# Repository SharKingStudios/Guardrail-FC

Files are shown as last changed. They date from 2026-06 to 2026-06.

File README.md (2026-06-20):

# Guardrail FC - A Flight Assist that helps you not crash!

### With a side of data logging and autopilot.

---

## Renders
*visuals because everyone loves eye candy.*

<p align="center">
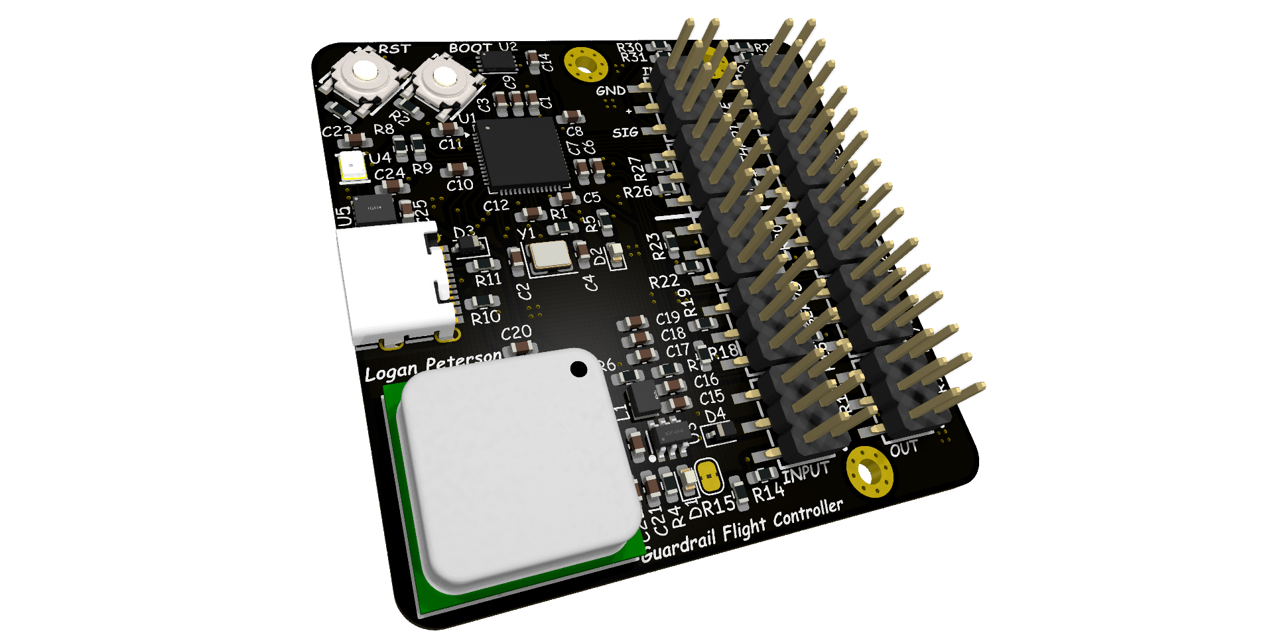
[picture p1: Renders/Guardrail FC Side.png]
Side PCB Render
  
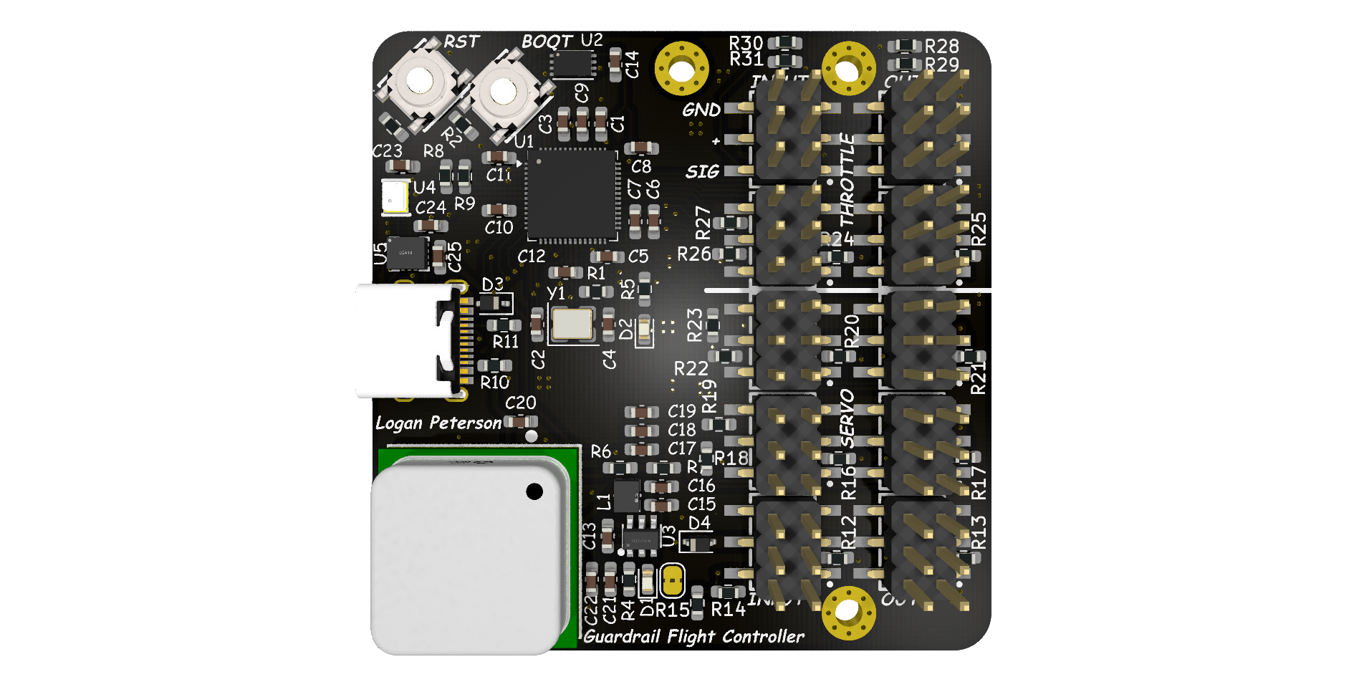
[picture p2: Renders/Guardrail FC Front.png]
Front PCB Render
  
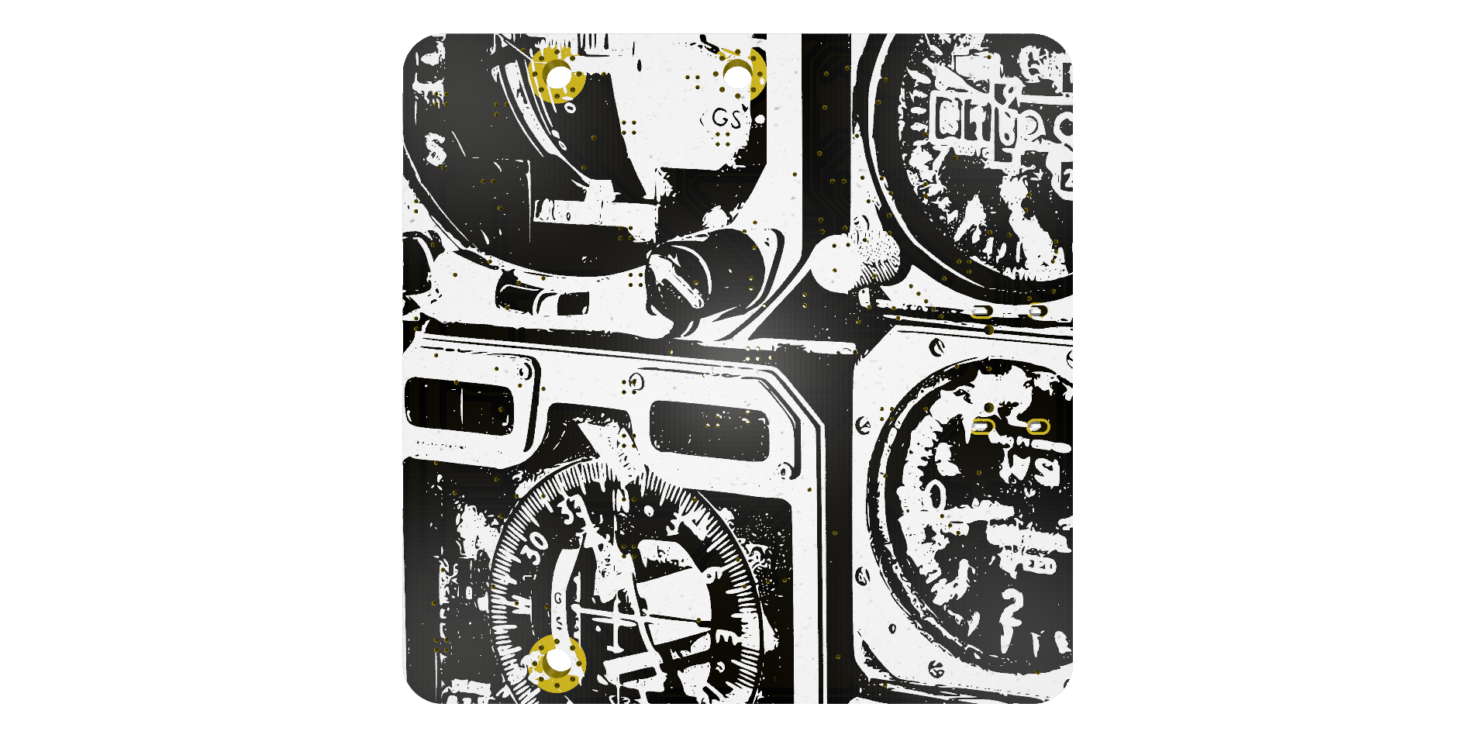
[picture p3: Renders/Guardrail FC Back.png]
Back PCB Render
  
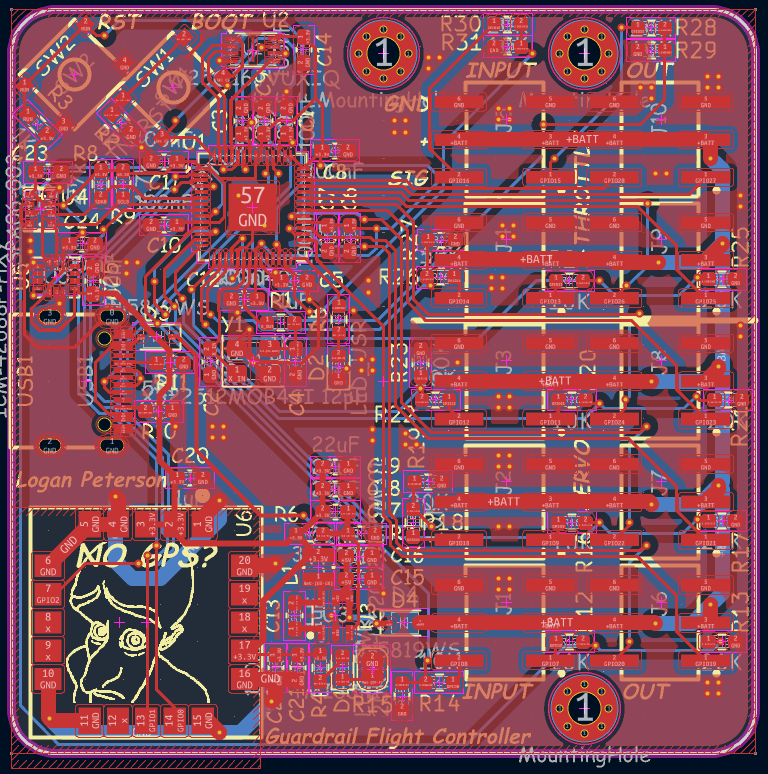
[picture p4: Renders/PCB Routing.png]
PCB Routing
  
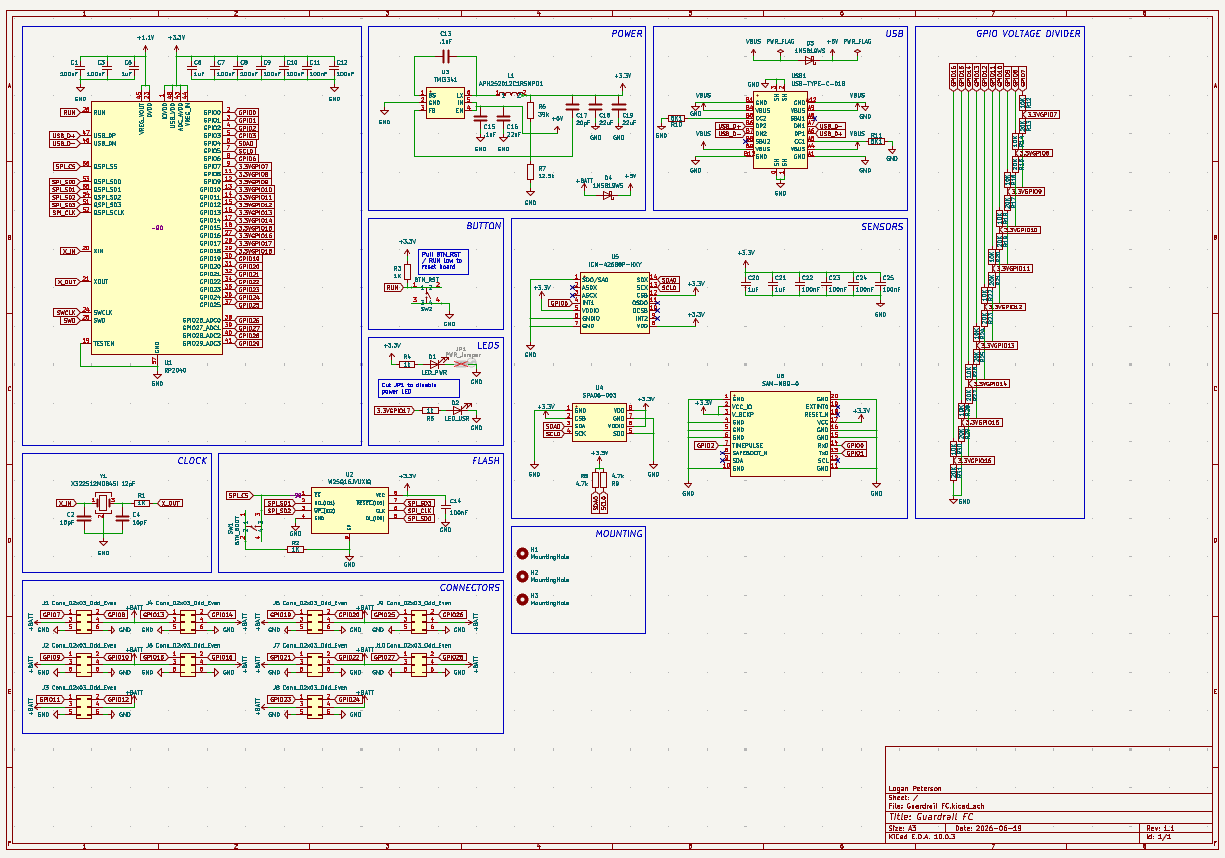
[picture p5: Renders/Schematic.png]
PCB Schematic
  
</p>

---

## BOM
All the sensing and thinky bits live **[here](/BOM.csv)**.

**Main characters:**
 - **Microcontroller:** RP2040
 - **Storage:** W25Q16JVUXIQ 16Mbit SPI flash
 - **Sensors:**
   - ICM-42688P-HXY 6-axis IMU
   - SAM-M8Q-0 GNSS module
   - SPA06-003 pressure sensor
 - **Misc:** Boot circuitry, pull-ups, decoupling, and other necessary magic

(See `BOM.csv` for full part values, footprints, and sourcing.)

---

## What is this?

The **Guardrail FC** is a **Flight Controller** built around a RP2040 microcontroller and a handful of sensors, designed to help you not crash your RC planes and drones!

It does this by sitting in the middle of the data signals between the RC reciever and the plane's control surfaces / throttle. The board will use the pilot's input to steer the plane, but will lock the plane to certain bank angles in order to prevent the plane from flipping upside down and crashing. The board also logs all the sensor data and pilot inputs to its onboard flash, which can be retrieved after the flight to analyze flight characteristics afterwards.

---

## How It Works

On startup, the board will continuously read the IMU, GNSS, and pressure sensors to get an idea of the plane's orientation, position, and altitude. From these readings, the board calculates what angles the servos need to be at to get to a certain desired angle using a PID loop.

The board will then read the pilot's input from the RC receiver, and use that to control the desired angle for the plane.

At a high level:
1. Read sensors to get current orientation, position, and altitude.
2. Read pilot input to get desired angle.
3. Use PID loop to calculate servo angles needed to achieve desired angle.
4. Output servo angles to control surfaces and throttle.

---

## Features

### Flight Assist
The main feature of the Guardrail FC is its flight assist capabilities. By using the IMU data, the board can determine the plane's current orientation and adjust the control surfaces to keep the plane within a certain bank angle, preventing it from flipping upside down and crashing.

### Data Logging
The board logs all sensor data and pilot inputs to its onboard flash memory. This allows you to analyze flight characteristics after the flight.

### Autopilot
In addition to flight assist, the firmware includes a guarded automatic-throttle mode that uses pressure altitude, vertical speed, aircraft attitude, and optional GNSS ground speed. Waypoint navigation remains future work.

---

## Firmware

The firmware lives in **[`Firmware/`](/Firmware/)** and is written in Python using MicroPython. Interrupt-driven input capture keeps all ten receiver channels live while the controller reads sensors and logs the flight.

See the [`Firmware/README.md`](/Firmware/README.md) for more details on how to set up the firmware and tune the board for your specific plane.

---

### Why?

Because crashing is bad, and this board helps you not crash! I've had an interest in RC planes and drones for a while, and by making this board, I can run whatever kind of firmware I want to create interesting flight characteristics. One of my friends recently created and crasshed their custom built plane, and I wanted to make something that might have been able to save it!

---

## Contributing

This is a personal project, but if you have any ideas or suggestions, feel free to open an issue or submit a pull request! I'm always open to feedback and improvements.

## Disclaimer

This project is still in development, and I have yet to test it in flight. Remember to test in a safe environment before flying with hardware from a random internet person! I am not responsible for any crashes or damage caused by this board. Use at your own risk!

<p align="center">
  Zine Page!
</p>

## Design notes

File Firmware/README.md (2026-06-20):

# Guardrail FC firmware

The v1 firmware is a configurable, fail-safe signal router, flight-assist controller, and flight logger for the Guardrail FC PCB. It uses MicroPython on the RP2040 so all 10 receiver PWM channels can be captured concurrently with hardware interrupts. The RP2040 CircuitPython port cannot provide enough simultaneous pulse-capture channels for this board's 10 inputs.

The safe factory profile is intentionally boring: J1-J3 pass straight through to J6-J8, J4/J5 throttle passes straight through to J9/J10, and both flight assist and AUTO throttle stay unselected until the airframe mapping and correction directions have been bench-tested.

## Files

- `main.py` initializes hardware and runs the real-time loop.
- `config.py` contains every normal airframe-specific choice and tuning value.
- `guardrail/channels.py` captures receiver pulses and drives servo PWM.
- `guardrail/control.py` performs routing, surface mixing, roll/pitch PID control, and guarded automatic throttle.
- `guardrail/sensors.py` reads the ICM-42688-P and SPA06-003 directly over I2C.
- `guardrail/gnss.py` parses GGA/RMC messages from the SAM-M8Q.
- `guardrail/logger.py` writes compact `.grf` flight logs to onboard flash.
- `tools/decode_log.py` converts a downloaded `.grf` file to CSV.

No third-party modules are needed on the controller.

## Install

1. Install the current RP2040 build of MicroPython while holding BOOT and connecting
   USB. The generic Raspberry Pi Pico build matches the RP2040 and 2 MiB W25Q16 flash.
2. Install `mpremote` on the computer: `python -m pip install mpremote`.
3. Copy `main.py`, `config.py`, and the entire `guardrail/` directory to the board.
4. Reset the board and watch the serial console. It prints the I2C scan, sensor status,
   gyro calibration result, log filename, and active mode.

Keep the aircraft motionless for roughly one second after reset. Outputs stay at their configured failsafe values during gyro calibration. Set `AUTO_GYRO_CALIBRATION = False` and enter measured `GYRO_BIAS_DPS` values if that startup pause is undesirable.

## Configure an airframe

Only edit `config.py`. The names stay tied to physical connector sides, so an output can be reassigned without remembering GPIO numbers.

For a one-to-one route, use:

```python
"J6_LEFT": _direct("J2_RIGHT")
```

For a reversed servo with roll stabilization mixed in:

```python
"J6_RIGHT": _direct("J1_RIGHT", assist={"roll": -1.0}, reverse=True)
```

For an elevon or V-tail, replace `source` with weighted `sources` in that output:

```python
"J6_LEFT": {
    "sources": {"J1_LEFT": 1.0, "J2_LEFT": 1.0},
    "assist": {"roll": 1.0, "pitch": 1.0},
    "reverse": False,
    "trim_us": 0,
    "min_us": 1000,
    "center_us": 1500,
    "max_us": 2000,
    "failsafe_us": 1500,
    "passthrough": False,
}
```

This same weighted mapping handles dual ailerons, flaperons, V-tails, canards, and multiple motor sections. A receiver channel may feed any number of outputs, and an output may combine any number of non-throttle inputs. A J4/J5 throttle may feed any number of J9/J10 motor outputs. Those routes remain exact pass-through in PASSTHROUGH and ASSIST modes; only AUTO may override the configured motor outputs.

Set `CONTROL_AXES` to the receiver channels that command roll and pitch. Add `roll`
or `pitch` assist weights only to surfaces that should correct that axis. Verify every
sign with the propellers removed:

- Roll the right wing down; the commanded surfaces must drive it back up.
- Raise the nose; the elevator correction must command nose-down.
- Move every transmitter stick and confirm the expected output and direction.
- Turn the transmitter off and confirm control surfaces center and all throttles go low.

Only after those checks should `DEFAULT_MODE` be changed to `"ASSIST"`. Prefer assigning
a spare three-position receiver channel to `MODE_CHANNEL`: low selects PASSTHROUGH,
middle selects ASSIST, and high selects AUTO. Begin with low `kp`, leave `ki` near zero, increase `kp` until the
aircraft responds firmly, add `kd` to reduce oscillation, and add only enough `ki` to
remove steady bias. Change one axis and one gain at a time.

`IMU_AXIS_MAP` handles rotated or inverted board installations without changing sensor
code. Confirm the printed/logged roll and pitch signs before enabling assist.

## Automatic throttle

AUTO uses every useful onboard measurement without pretending the board has an
airspeed sensor:

- SPA06 pressure altitude is the primary feedback. AUTO captures the current altitude
  when selected unless `target_altitude_m` is configured explicitly.
- Vertical speed derived from pressure altitude damps throttle changes and reduces
  overshoot.
- ICM-42688 roll adds throttle in a bank, while positive pitch adds configurable climb
  feed-forward.
- SAM-M8Q ground speed can add a bounded correction when `groundspeed_target_mps` is
  configured. It is disabled by default because ground speed is not stall-protecting
  airspeed in wind.

All airframe values are in `AUTO_THROTTLE` in `config.py`. Tune `cruise_us`, `min_us`,
and `max_us` first with AUTO disabled. Then set a conservative `slew_rate_us_per_s`,
start with altitude `ki` at zero, and tune altitude `kp` at a safe height. Add vertical
speed damping, then only enough integral to remove a steady altitude error. Bank and
pitch compensation are feed-forward terms and should be tuned last.

The `outputs` map selects which J9/J10 motor sections AUTO controls and supplies a
per-motor trim. Outputs not listed remain pilot pass-through. AUTO will arm only on the
transition into AUTO when:

- every receiver channel feeding an automatic motor output is fresh;
- a valid barometric altitude is available (or explicitly enabled GNSS fallback);
- the IMU is healthy when `require_imu` is true; and
- GNSS is valid when GNSS ground-speed control is configured.

If any required input disappears after engagement, all automatic motor outputs go to
their configured low-throttle failsafe and AUTO will not re-arm until the mode switch is
toggled out and back. Moving any pilot throttle above `pilot_override_us` immediately
restores raw pilot throttle and latches that override until AUTO is toggled off/on.
Commands are bounded and slew-limited during normal automatic operation; receiver loss
still takes priority over every override.

Before fitting propellers, select AUTO and verify: throttle enters without a jump,
raising the board decreases the altitude-error command, banking adds only the expected
small compensation, pilot override restores every raw throttle channel, sensor failure
commands low throttle, and re-arming requires a deliberate mode-switch cycle.

## Logs

Logs contain mode (including AUTO), health flags, AUTO-active/pilot-override flags,
attitude, gyro and temperature, pressure altitude, GNSS position/speed/fix, all 10 raw
receiver pulses, and all 10 commanded output pulses. They rotate at 512 KiB; with the
default 10 Hz rate, each file holds roughly ten minutes. Logging stops safely if flash
fills; the control loop continues.

Copy a log from `/logs` with `mpremote`, then decode it on the computer:

```text
python tools/decode_log.py flight_000.grf
```

This produces `flight_000.csv`. Remove old `.grf` files from the controller between test sessions; the W25Q16 is also the firmware/filesystem flash, not a separate recorder.

## Safety status

This is unflown experimental firmware. The LED blinks quickly while any configured
output is in failsafe and slowly when all routed inputs are fresh. Always bench-test with propellers removed, verify PWM limits for every servo/ESC, and test receiver and sensor loss before flight. AUTO throttle is altitude hold, not stall protection or a complete navigation autopilot. A software pass-through cannot protect against total MCU or power failure; a production design that requires that behavior needs an external hardware bypass.

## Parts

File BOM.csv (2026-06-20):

Item | Qty | Price Ea. | Price total (MOQ) | Product Link
0.1uF/100nF capacitor 0603 | 15 | 0.0101 | 1.01 | https://www.lcsc.com/product-detail/C15725.html
15pF capacitor 0603 | 2 | 0.0022 | 0.22 | https://www.lcsc.com/product-detail/C1548.html
1uF capacitor 0603 | 4 | 0.0089 | 0.45 | https://www.lcsc.com/product-detail/C95843.html
22uF capacitor 0603 | 3 | 0.23 | 0.45 | https://www.lcsc.com/product-detail/C59461.html
20pF capacitor 0603 | 1 | 0.0047 | 0.047 | https://www.lcsc.com/product-detail/C105621.html
LED 0603 | 2 | 0.0073 | 0.73 | https://www.lcsc.com/product-detail/C2286.html
1N5819WS Schottky diode SOD-323 | 2 | 0.0107 | 0.54 | https://www.lcsc.com/product-detail/C191023.html
ZHOURI PZ2.54-2*20-SMT | 2 | 0.24 | 1.2 | https://www.lcsc.com/product-detail/C5378173.html
APH252012C1R5MP01 1.5uH SMD inductor | 1 | 0.034 | 0.68 | https://www.lcsc.com/product-detail/C42455360.html
1k resistor 0603 | 5 | 0.0054 | 0.54 | https://www.lcsc.com/product-detail/C2907002.html
39k resistor 0603 | 1 | 0.001 | 0.10 | https://www.lcsc.com/product-detail/C54921034.html
12.5k resistor 0603 | 1 | 0.0016 | 0.16 | https://www.lcsc.com/product-detail/C22866.html
4.7k resistor 0603 | 2 | 0.0017 | 0.17 | https://www.lcsc.com/product-detail/C105428.html
5.1k resistor 0603 | 2 | 0.0022 | 0.22 | https://www.lcsc.com/product-detail/C2907044.html
10k resistor 0603 | 10 | 0.0014 | 0.14 | https://www.lcsc.com/product-detail/C2930027.html
20k resistor 0603 | 10 | 0.0019 | 0.19 | https://www.lcsc.com/product-detail/C2907011.html
LXW-52X52X2-SMD tactile switch | 2 | 0.023 | 0.45 | https://www.lcsc.com/product-detail/C53447014.html
RP2040 microcontroller QFN-56 | 1 | 0.99 | 0.99 | https://www.lcsc.com/product-detail/C2040.html
W25Q16JVUXIQ 16Mbit SPI flash USON-8 | 1 | 2.39 | 11.99 | https://www.lcsc.com/product-detail/C2843335.html
TMI3341 DC-DC converter SOT-23-6 | 1 | 0.13 | 0.68 | https://www.lcsc.com/product-detail/C5182732.html
SPA06-003 pressure sensor LGA-8 | 1 | 0.78 | 0.78 | https://www.lcsc.com/product-detail/C30589048.html
ICM-42688P-HXY IMU LGA-14 | 1 | 3.53 | 3.53 | https://www.lcsc.com/product-detail/C46550687.html
SAM-M8Q-0 GNSS module LCC-20 | 1 | 14.49 | 14.49 | https://www.lcsc.com/product-detail/C5447387.html
USB-TYPE-C-018 USB-C receptacle | 1 | 0.0568 | 0.57 | https://www.lcsc.com/product-detail/C2927038.html
X322512MOB4SI 12pF crystal 3225 4-pin | 1 | 0.0966 | 0.48 | https://www.lcsc.com/product-detail/C70565.html
LCSC Parts Total |  |  | 40.81
LCSC Shipping |  |  | 5.00 | (Bundled with another order)
LCSC Total |  |  | 45.81
JLCPCB 10x10cm 2-layer PCB | 1 | 2.00 | 2.00 | https://jlcpcb.com
JLCPCB 10x10cm stencil | 1 | 7.50 | 7.50 | https://jlcpcb.com
JLCPCB Shipping |  |  | 16.00 | https://jlcpcb.com
JLCPCB Taxes |  |  | 4.00 | https://jlcpcb.com
JLCPCB Total |  |  | 29.50 | https://jlcpcb.com
Overall Total |  |  | 75.31

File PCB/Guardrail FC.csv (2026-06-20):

Reference | Qty | Value | DNP | Exclude from BOM | Exclude from Board | Footprint | Datasheet
C1,C3,C7,C8,C9,C10,C11,C12,C14,C22,C23,C24,C25 | 13 | 100nF |  |  |  | Capacitor_SMD:C_0603_1608Metric_Pad1.08x0.95mm_HandSolder
C2,C4 | 2 | 15pF |  |  |  | Capacitor_SMD:C_0603_1608Metric_Pad1.08x0.95mm_HandSolder
C5,C6,C20,C21 | 4 | 1uF |  |  |  | Capacitor_SMD:C_0603_1608Metric_Pad1.08x0.95mm_HandSolder
C13,C15 | 2 | .1uF |  |  |  | Capacitor_SMD:C_0603_1608Metric_Pad1.08x0.95mm_HandSolder
C16,C18,C19 | 3 | 22uF |  |  |  | Capacitor_SMD:C_0603_1608Metric_Pad1.08x0.95mm_HandSolder
C17 | 1 | 20pF |  |  |  | Capacitor_SMD:C_0603_1608Metric_Pad1.08x0.95mm_HandSolder
D1 | 1 | LED_PWR |  |  |  | LED_SMD:LED_0603_1608Metric
D2 | 1 | LED_USR |  |  |  | LED_SMD:LED_0603_1608Metric
D3,D4 | 2 | 1N5819WS |  |  |  | Diode_SMD:D_SOD-323 | https://datasheet.lcsc.com/lcsc/2204281430_Guangdong-Hottech-1N5819WS_C191023.pdf
J1,J2,J3,J4,J5,J6,J7,J8,J9,J10 | 10 | Conn_02x03_Odd_Even |  |  |  | imported_components:HDR-SMD_6P-P2.54-V
JP1 | 1 | PWR_Jumper | DNP |  |  | Jumper:SolderJumper-2_P1.3mm_Bridged2Bar_RoundedPad1.0x1.5mm
L1 | 1 | APH252012C1R5MP01 |  |  |  | easyeda2kicad:IND-SMD_APH252012C3R3MP01 | https://www.lcsc.com/datasheet/C42455360.pdf
R1,R2,R3 | 3 | 1K |  |  |  | Resistor_SMD:R_0603_1608Metric_Pad0.98x0.95mm_HandSolder
R4,R5 | 2 | 1k |  |  |  | Resistor_SMD:R_0603_1608Metric_Pad0.98x0.95mm_HandSolder
R6 | 1 | 39k |  |  |  | Resistor_SMD:R_0603_1608Metric_Pad0.98x0.95mm_HandSolder
R7 | 1 | 12.5k |  |  |  | Resistor_SMD:R_0603_1608Metric_Pad0.98x0.95mm_HandSolder
R8,R9 | 2 | 4.7k |  |  |  | Resistor_SMD:R_0603_1608Metric_Pad0.98x0.95mm_HandSolder
R10,R11 | 2 | 5K1 |  |  |  | Resistor_SMD:R_0603_1608Metric_Pad0.98x0.95mm_HandSolder
R12,R14,R16,R18,R20,R22,R24,R26,R28,R30 | 10 | 10K |  |  |  | Resistor_SMD:R_0603_1608Metric_Pad0.98x0.95mm_HandSolder
R13,R15,R17,R19,R21,R23,R25,R27,R29,R31 | 10 | 20K |  |  |  | Resistor_SMD:R_0603_1608Metric_Pad0.98x0.95mm_HandSolder
SW1 | 1 | BTN_BOOT |  |  |  | imported_lcsc:SW-SMD_4P-L5.2-W5.2-P5.80-LS6.4 | https://www.lcsc.com/datasheet/C53447014.pdf
SW2 | 1 | BTN_RST |  |  |  | imported_lcsc:SW-SMD_4P-L5.2-W5.2-P5.80-LS6.4 | https://www.lcsc.com/datasheet/C53447014.pdf
U1 | 1 | RP2040 |  |  |  | Package_DFN_QFN:QFN-56-1EP_7x7mm_P0.4mm_EP3.2x3.2mm | https://datasheets.raspberrypi.com/rp2040/rp2040-datasheet.pdf
U2 | 1 | W25Q16JVUXIQ |  |  |  | Package_SON:Winbond_USON-8-1EP_3x2mm_P0.5mm_EP0.2x1.6mm
U3 | 1 | TMI3341 |  |  |  | imported_lcsc:SOT-23-6_L2.9-W1.6-P0.95-LS2.8-BL | https://www.lcsc.com/datasheet/C5182732.pdf
U4 | 1 | SPA06-003 |  |  |  | imported_lcsc:LGA-8_L2.5-W2.0-P0.65_SPA06-003 | https://www.lcsc.com/datasheet/C30589048.pdf
U5 | 1 | ICM-42688P-HXY |  |  |  | imported_lcsc:LGA-14_L3.0-W2.5-P0.50-TL | https://www.lcsc.com/datasheet/C46550687.pdf
U6 | 1 | SAM-M8Q-0 |  |  |  | imported_lcsc:LCC-20_L15.5-W15.5-P1.90_SAM-M10Q-00B | https://www.lcsc.com/datasheet/C5447387.pdf
USB1 | 1 | USB-TYPE-C-018 |  |  |  | imported_lcsc:USB-C_SMD-TYPE-C-31-M-12 | https://www.lcsc.com/datasheet/C2927038.pdf
Y1 | 1 | X322512MOB4SI 12pF |  |  |  | Crystal:Crystal_SMD_3225-4Pin_3.2x2.5mm

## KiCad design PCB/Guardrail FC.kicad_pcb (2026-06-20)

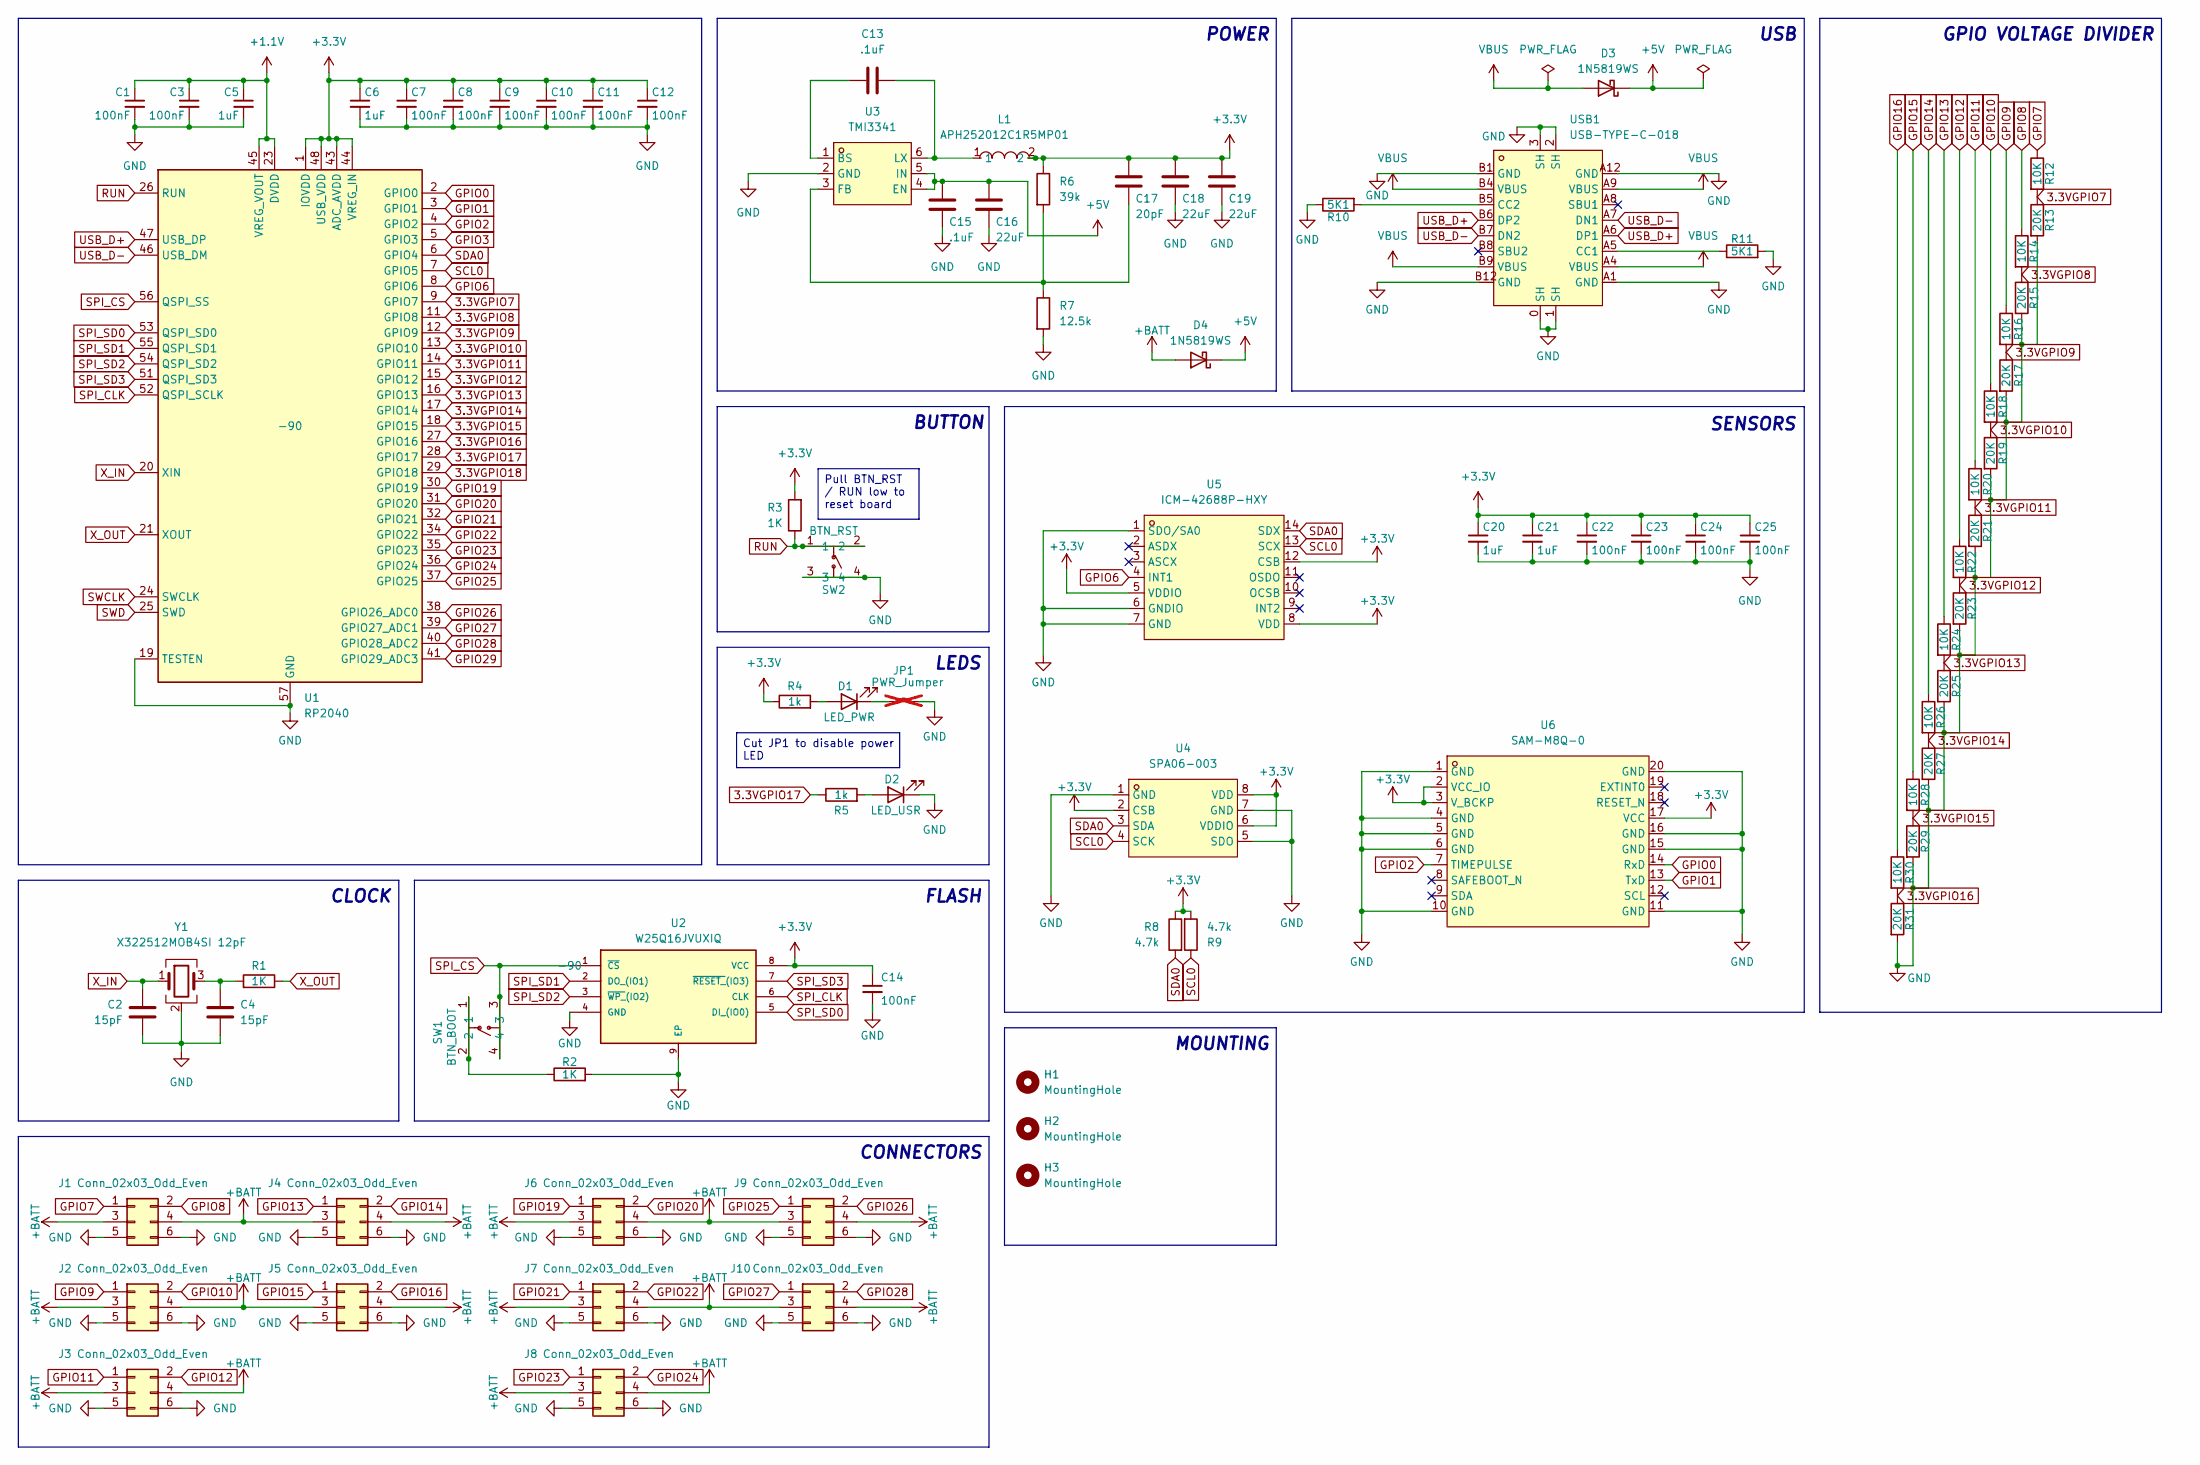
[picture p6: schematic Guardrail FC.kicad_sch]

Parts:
C1, C3, C7, C8, C9, C10, C11, C12, C14, C22, C23, C24, C25: 100nF; C_0603_1608Metric_Pad1.08x0.95mm_HandSolder; LCSC C1525
C2, C4: 15pF; C_0603_1608Metric_Pad1.08x0.95mm_HandSolder; LCSC C1548
C5, C6: 1uF; C_0603_1608Metric_Pad1.08x0.95mm_HandSolder; LCSC C52923
C13, C15: .1uF; C_0603_1608Metric_Pad1.08x0.95mm_HandSolder
C16, C18, C19: 22uF; C_0603_1608Metric_Pad1.08x0.95mm_HandSolder
C17: 20pF; C_0603_1608Metric_Pad1.08x0.95mm_HandSolder
C20, C21: 1uF; C_0603_1608Metric_Pad1.08x0.95mm_HandSolder; LCSC C1525
D1: LED_PWR; LED_0603_1608Metric; LCSC C2286
D2: LED_USR; LED_0603_1608Metric; LCSC C2286
D3, D4: 1N5819WS; D_SOD-323; LCSC C191023
H1, H2, H3: MountingHole; MountingHole_2.2mm_M2_Pad_Via
J1, J2, J3, J4, J5, J6, J7, J8, J9, J10: Conn_02x03_Odd_Even; HDR-SMD_6P-P2.54-V
JP1: PWR_Jumper; SolderJumper-2_P1.3mm_Bridged2Bar_RoundedPad1.0x1.5mm; not fitted
L1: APH252012C1R5MP01; IND-SMD_APH252012C3R3MP01; MPN APH252012C1R5MP01; LCSC Part C42455360
R1, R2, R3: 1K; R_0603_1608Metric_Pad0.98x0.95mm_HandSolder; LCSC C11702
R4, R5: 1k; R_0603_1608Metric_Pad0.98x0.95mm_HandSolder; LCSC C11702
R6: 39k; R_0603_1608Metric_Pad0.98x0.95mm_HandSolder
R7: 12.5k; R_0603_1608Metric_Pad0.98x0.95mm_HandSolder
R8, R9: 4.7k; R_0603_1608Metric_Pad0.98x0.95mm_HandSolder
R10, R11: 5K1; R_0603_1608Metric_Pad0.98x0.95mm_HandSolder; LCSC C25905
R12, R14, R16, R18, R20, R22, R24, R26, R28, R30: 10K; R_0603_1608Metric_Pad0.98x0.95mm_HandSolder; LCSC C11702
R13, R15, R17, R19, R21, R23, R25, R27, R29, R31: 20K; R_0603_1608Metric_Pad0.98x0.95mm_HandSolder; LCSC C11702
SW1: BTN_BOOT; SW-SMD_4P-L5.2-W5.2-P5.80-LS6.4; MPN LXW-52X52X2-SMD; LCSC Part C53447014
SW2: BTN_RST; SW-SMD_4P-L5.2-W5.2-P5.80-LS6.4; MPN LXW-52X52X2-SMD; LCSC Part C53447014
U1: RP2040; QFN-56-1EP_7x7mm_P0.4mm_EP3.2x3.2mm; LCSC C2040
U2: W25Q16JVUXIQ; Winbond_USON-8-1EP_3x2mm_P0.5mm_EP0.2x1.6mm; LCSC C2843335
U3: TMI3341; SOT-23-6_L2.9-W1.6-P0.95-LS2.8-BL; MPN TMI3341; LCSC Part C5182732
U4: SPA06-003; LGA-8_L2.5-W2.0-P0.65_SPA06-003; MPN SPA06-003; LCSC Part C30589048
U5: ICM-42688P-HXY; LGA-14_L3.0-W2.5-P0.50-TL; MPN ICM-42688P-HXY; LCSC Part C46550687
U6: SAM-M8Q-0; LCC-20_L15.5-W15.5-P1.90_SAM-M10Q-00B; MPN SAM-M8Q-0; LCSC Part C5447387
USB1: USB-TYPE-C-018; USB-C_SMD-TYPE-C-31-M-12; MPN USB-TYPE-C-018; LCSC Part C2927038
Y1: X322512MOB4SI 12pF; Crystal_SMD_3225-4Pin_3.2x2.5mm; LCSC C70565

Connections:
3.3VGPIO7: R12.2, R13.1, U1.9 (GPIO7)
3.3VGPIO8: R14.2, R15.1, U1.11 (GPIO8)
3.3VGPIO9: R16.2, R17.1, U1.12 (GPIO9)
3.3VGPIO10: R18.2, R19.1, U1.13 (GPIO10)
3.3VGPIO11: R20.2, R21.1, U1.14 (GPIO11)
3.3VGPIO12: R22.2, R23.1, U1.15 (GPIO12)
3.3VGPIO13: R24.2, R25.1, U1.16 (GPIO13)
3.3VGPIO14: R26.2, R27.1, U1.17 (GPIO14)
3.3VGPIO15: R28.2, R29.1, U1.18 (GPIO15)
3.3VGPIO16: R30.2, R31.1, U1.27 (GPIO16)
3.3VGPIO17: R5.1, U1.28 (GPIO17)
3.3VGPIO18: U1.29 (GPIO18)
+1.1V: C1.1, C3.1, C5.1, U1.23 (DVDD), U1.45 (VREG_VOUT), U1.50 (DVDD)
+3.3V: C6.1, C7.1, C8.1, C9.1, C10.1, C11.1, C12.1, C14.1, C17.2, C18.2, C19.2, C20.1, C21.1, C22.1, C23.1, C24.1, C25.1, L1.2, R3.2, R4.1, R6.1, R8.1, R9.2, U1.1 (IOVDD), U1.10 (IOVDD), U1.22 (IOVDD), U1.33 (IOVDD), U1.42 (IOVDD), U1.43 (ADC_AVDD), U1.44 (VREG_IN), U1.48 (USB_VDD), U1.49 (IOVDD), U2.8 (VCC), U4.2 (CSB), U4.6 (VDDIO), U4.8 (VDD), U5.5 (VDDIO), U5.8 (VDD), U5.12 (CSB), U6.2 (VCC_IO), U6.3 (V_BCKP), U6.17 (VCC)
+5V: C15.2, C16.2, D3.1 (K), D4.1 (K), U3.4 (EN), U3.5 (IN)
+BATT: D4.2 (A), J1.3, J1.4, J2.3, J2.4, J3.3, J3.4, J4.3, J4.4, J5.3, J5.4, J6.3, J6.4, J7.3, J7.4, J8.3, J8.4, J9.3, J9.4, J10.3, J10.4
GND: C1.2, C2.1, C3.2, C4.2, C5.2, C6.2, C7.2, C8.2, C9.2, C10.2, C11.2, C12.2, C14.2, C15.1, C16.1, C18.1, C19.1, C20.2, C21.2, C22.2, C23.2, C24.2, C25.2, D2.1 (K), J1.5, J1.6, J2.5, J2.6, J3.5, J3.6, J4.5, J4.6, J5.5, J5.6, J6.5, J6.6, J7.5, J7.6, J8.5, J8.6, J9.5, J9.6, J10.5, J10.6, JP1.2 (B), R2.2, R7.2, R10.1, R11.2, R13.2, R15.2, R17.2, R19.2, R21.2, R23.2, R25.2, R27.2, R29.2, R31.2, SW2.3, SW2.4, U1.19 (TESTEN), U1.57 (GND), U2.4 (GND), U2.9 (EP), U3.2 (GND), U4.1 (GND), U4.5 (SDO), U4.7 (GND), U5.1 (SDO/SA0), U5.6 (GNDIO), U5.7 (GND), U6.1 (GND), U6.4 (GND), U6.5 (GND), U6.6 (GND), U6.10 (GND), U6.11 (GND), U6.15 (GND), U6.16 (GND), U6.20 (GND), USB1.0 (SH), USB1.1 (SH), USB1.2 (SH), USB1.3 (SH), USB1.A1 (GND), USB1.A12 (GND), USB1.B1 (GND), USB1.B12 (GND), Y1.2 (G), Y1.4 (G)
GPIO0: U1.2 (GPIO0), U6.14 (RxD)
GPIO1: U1.3 (GPIO1), U6.13 (TxD)
GPIO2: U1.4 (GPIO2), U6.7 (TIMEPULSE)
GPIO3: U1.5 (GPIO3)
GPIO6: U1.8 (GPIO6), U5.4 (INT1)
GPIO7: J1.1, R12.1
GPIO8: J1.2, R14.1
GPIO9: J2.1, R16.1
GPIO10: J2.2, R18.1
GPIO11: J3.1, R20.1
GPIO12: J3.2, R22.1
GPIO13: J4.1, R24.1
GPIO14: J4.2, R26.1
GPIO15: J5.1, R28.1
GPIO16: J5.2, R30.1
GPIO19: J6.1, U1.30 (GPIO19)
GPIO20: J6.2, U1.31 (GPIO20)
GPIO21: J7.1, U1.32 (GPIO21)
GPIO22: J7.2, U1.34 (GPIO22)
GPIO23: J8.1, U1.35 (GPIO23)
GPIO24: J8.2, U1.36 (GPIO24)
GPIO25: J9.1, U1.37 (GPIO25)
GPIO26: J9.2, U1.38 (GPIO26_ADC0)
GPIO27: J10.1, U1.39 (GPIO27_ADC1)
GPIO28: J10.2, U1.40 (GPIO28_ADC2)
GPIO29: U1.41 (GPIO29_ADC3)
unnamed: C4.1, R1.2, Y1.3
unnamed: D1.2 (A), R4.2
unnamed: D1.1 (K), JP1.1 (A)
unnamed: D2.2 (A), R5.2
unnamed: R2.1, SW1.1, SW1.2
unnamed: C13.1, U3.1 (BS)
unnamed: C17.1, R6.2, R7.1, U3.3 (FB)
unnamed: C13.2, L1.1, U3.6 (LX)
unnamed: R11.1, USB1.A5 (CC1)
unnamed: R10.2, USB1.B5 (CC2)
RUN: R3.1, SW2.1, SW2.2, U1.26 (RUN)
SCL0: R9.1, U1.7 (GPIO5), U4.4 (SCK), U5.13 (SCX)
SDA0: R8.2, U1.6 (GPIO4), U4.3 (SDA), U5.14 (SDX)
SPI_CLK: U1.52 (QSPI_SCLK), U2.6 (CLK)
SPI_CS: SW1.3, SW1.4, U1.56 (QSPI_SS), U2.1 (~CS)
SPI_SD0: U1.53 (QSPI_SD0), U2.5 (DI_(IO0))
SPI_SD1: U1.55 (QSPI_SD1), U2.2 (DO_(IO1))
SPI_SD2: U1.54 (QSPI_SD2), U2.3 (~WP_(IO2))
SPI_SD3: U1.51 (QSPI_SD3), U2.7 (~RESET_(IO3))
SWCLK: U1.24 (SWCLK)
SWD: U1.25 (SWD)
USB_D+: U1.47 (USB_DP), USB1.A6 (DP1), USB1.B6 (DP2)
USB_D-: U1.46 (USB_DM), USB1.A7 (DN1), USB1.B7 (DN2)
VBUS: D3.2 (A), USB1.A4 (VBUS), USB1.A9 (VBUS), USB1.B4 (VBUS), USB1.B9 (VBUS)
X_IN: C2.2, U1.20 (XIN), Y1.1
X_OUT: R1.1, U1.21 (XOUT)

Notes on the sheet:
BUTTON
MOUNTING
GPIO VOLTAGE DIVIDER
CONNECTORS
USB
CLOCK
POWER
SENSORS
LEDS
FLASH
Cut JP1 to disable power LED
Pull BTN_RST / RUN low to reset board

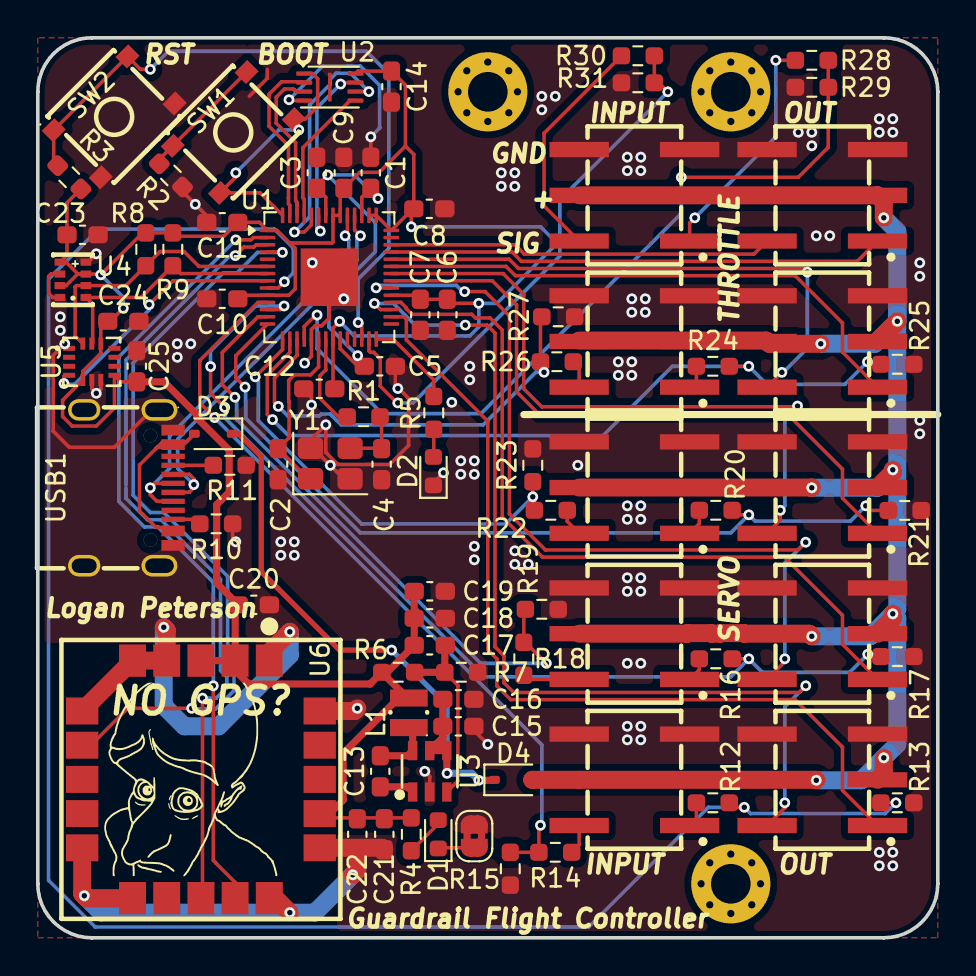
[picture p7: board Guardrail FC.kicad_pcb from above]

Board: 2 copper layers, 50.0 x 50.0 mm, 86 parts (0 on the bottom side), 64 nets.

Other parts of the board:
NO GPS?: LOGO

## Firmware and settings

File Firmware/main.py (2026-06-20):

"""Guardrail FC boot entry point (MicroPython on RP2040)."""

import time
import micropython
from machine import I2C, Pin, UART

import config
from guardrail.channels import Receiver, ServoOutputs
from guardrail.control import AttitudeAssist, AutoThrottle, OutputMixer
from guardrail.gnss import GNSS
from guardrail.logger import FlightLogger
from guardrail.sensors import ICM42688, SPA06
from guardrail.validation import validate


FLAG_IMU = 1 << 0
FLAG_BAROMETER = 1 << 1
FLAG_GNSS = 1 << 2
FLAG_RECEIVER = 1 << 3
FLAG_FAILSAFE = 1 << 4
FLAG_AUTO_ACTIVE = 1 << 5
FLAG_AUTO_OVERRIDE = 1 << 6


def due(now, deadline):
    return time.ticks_diff(now, deadline) >= 0


def selected_mode(inputs, fresh):
    if config.MODE_CHANNEL is None:
        return config.DEFAULT_MODE
    if not fresh.get(config.MODE_CHANNEL, False):
        return "PASSTHROUGH"
    pulse = inputs[config.MODE_CHANNEL]
    if pulse >= config.MODE_AUTO_THRESHOLD_US:
        return "AUTO"
    if pulse >= config.MODE_ASSIST_THRESHOLD_US:
        return "ASSIST"
    return "PASSTHROUGH"


def automatic_altitude(barometer, gnss):
    if barometer and barometer.sample_revision:
        return barometer.altitude_m, "BAROMETER", barometer.sample_revision
    if (
        config.AUTO_THROTTLE["allow_gnss_altitude_fallback"]
        and gnss
        and gnss.valid
        and gnss.altitude_m is not None
    ):
        return gnss.altitude_m, "GNSS", gnss.altitude_revision
    return None, None, None


def automatic_health(imu, gnss, altitude_m, throttle_sources, fresh):
    if not config.AUTO_THROTTLE["enabled"]:
        return "disabled in config"
    if any(not fresh.get(source, False) for source in throttle_sources):
        return "throttle receiver input stale"
    if altitude_m is None:
        return "no valid altitude"
    if config.AUTO_THROTTLE["require_imu"] and imu is None:
        return "IMU unavailable"
    if config.AUTO_THROTTLE["groundspeed_target_mps"] is not None and not (gnss and gnss.valid):
        return "GNSS groundspeed unavailable"
    return None


def initialize_sensor(label, constructor):
    try:
        sensor = constructor()
        print(label, "ready")
        return sensor
    except Exception as error:
        print(label, "unavailable:", error)
        return None


def main():
    micropython.alloc_emergency_exception_buf(100)
    validate(config)
    led = Pin(config.STATUS_LED_PIN, Pin.OUT, value=0)
    outputs = ServoOutputs(config.OUTPUT_PINS, config.OUTPUTS, config.PWM_FRAME_US)
    receiver = Receiver(
        config.INPUT_PINS,
        config.PWM_MIN_VALID_US,
        config.PWM_MAX_VALID_US,
        config.INPUT_TIMEOUT_MS,
    )
    mixer = OutputMixer(config.OUTPUTS, config.DEFAULT_INPUT_CALIBRATION, config.INPUT_CALIBRATION)
    assist = AttitudeAssist(config.CONTROL_AXES, config.PID, config.DEFAULT_INPUT_CALIBRATION, config.INPUT_CALIBRATION)
    automatic_throttle = AutoThrottle(config.AUTO_THROTTLE)
    automatic_outputs = tuple(config.AUTO_THROTTLE["outputs"])
    automatic_sources = tuple({config.OUTPUTS[output]["source"] for output in automatic_outputs})

    i2c = I2C(0, sda=Pin(4), scl=Pin(5), freq=400000)
    print("I2C devices:", [hex(address) for address in i2c.scan()])
    imu = initialize_sensor(
        "ICM-42688-P",
        lambda: ICM42688(i2c, config.IMU_AXIS_MAP, config.COMPLEMENTARY_ALPHA, config.GYRO_BIAS_DPS),
    )
    barometer = initialize_sensor("SPA06-003", lambda: SPA06(i2c, config.SEA_LEVEL_PRESSURE_PA))
    gnss = initialize_sensor(
        "SAM-M8Q",
        lambda: GNSS(
            UART(0, baudrate=config.GNSS_BAUDRATE, tx=Pin(0), rx=Pin(1), timeout=0),
            config.GNSS_FIX_TIMEOUT_MS,
        ),
    )

    if imu and config.AUTO_GYRO_CALIBRATION:
        print("Keep aircraft still: calibrating gyro")
        try:
            imu.calibrate_gyro(config.GYRO_CALIBRATION_SAMPLES)
            print("Gyro bias:", imu.bias)
        except Exception as error:
            print("Gyro calibration failed:", error)
            imu = None

    logger = FlightLogger(
        config.LOG_DIRECTORY,
        config.MAX_LOG_BYTES,
        config.FLUSH_INTERVAL_MS,
        config.INPUT_ORDER,
        config.OUTPUT_ORDER,
    )

    attitude = (0.0, 0.0)
    gyro = (0.0, 0.0, 0.0)
    imu_temperature = 0.0
    corrections = {"roll": 0.0, "pitch": 0.0}
    input_values = {name: 0 for name in config.INPUT_ORDER}
    fresh = {name: False for name in config.INPUT_ORDER}
    failed_outputs = list(config.OUTPUT_ORDER)
    mode = "PASSTHROUGH"
    previous_mode = "PASSTHROUGH"
    last_automatic_reason = None

    now = time.ticks_ms()
    next_imu = now
    next_baro = now
    next_control = now
    next_log = now
    last_control = time.ticks_us()
    blink_deadline = now
    blink_state = False

    imu_period = max(1, 1000 // config.IMU_HZ)
    baro_period = max(1, 1000 // config.BAROMETER_HZ)
    control_period = max(1, 1000 // config.CONTROL_HZ)
    log_period = max(1, 1000 // config.LOG_HZ)

    print("Guardrail FC running; default mode:", config.DEFAULT_MODE)
    while True:
        now = time.ticks_ms()
        if gnss:
            gnss.update()

        if imu and due(now, next_imu):
            next_imu = time.ticks_add(next_imu, imu_period)
            try:
                attitude, gyro = imu.update()
                imu_temperature = imu.temperature_c
            except Exception as error:
                print("IMU stopped:", error)
                imu = None
                assist.reset()

        if barometer and due(now, next_baro):
            next_baro = time.ticks_add(next_baro, baro_period)
            try:
                barometer.update()
            except Exception as error:
                print("Barometer stopped:", error)
                barometer = None

        if due(now, next_control):
            next_control = time.ticks_add(next_control, control_period)
            input_values, fresh = receiver.snapshot()
            previous_mode = mode
            mode = selected_mode(input_values, fresh)
            control_now = time.ticks_us()
            dt = time.ticks_diff(control_now, last_control) / 1000000.0
            last_control = control_now
            if mode in ("ASSIST", "AUTO") and imu:
                corrections = assist.update(input_values, fresh, attitude, gyro, dt)
            else:
                assist.reset()
                corrections = {"roll": 0.0, "pitch": 0.0}
            throttle_overrides = {}
            forced_failsafe = ()
            if mode != "AUTO":
                if previous_mode == "AUTO":
                    automatic_throttle.disengage()
            else:
                altitude_m, altitude_source, altitude_revision = automatic_altitude(barometer, gnss)
                health_error = automatic_health(imu, gnss, altitude_m, automatic_sources, fresh)
                pilot_values = [input_values[source] for source in automatic_sources]
                pilot_average = sum(pilot_values) / len(pilot_values)
                pilot_highest = max(pilot_values)

                if previous_mode != "AUTO":
                    if health_error is None:
                        automatic_throttle.engage(
                            altitude_m,
                            altitude_source,
                            altitude_revision,
                            pilot_average,
                        )
                    else:
                        automatic_throttle.abort("entry blocked: " + health_error)

                if automatic_throttle.active:
                    if health_error is not None:
                        automatic_throttle.abort(health_error)
                    else:
                        ground_speed = gnss.speed_mps if gnss and gnss.valid else None
                        automatic_throttle.update(
                            altitude_m,
                            altitude_source,
                            altitude_revision,
                            attitude,
                            ground_speed,
                            pilot_highest,
                            dt,
                        )

                if automatic_throttle.active:
                    throttle_overrides = automatic_throttle.output_overrides(config.OUTPUTS)
                elif not automatic_throttle.override_latched:
                    throttle_overrides = automatic_throttle.failsafe_overrides(config.OUTPUTS)
                    forced_failsafe = automatic_outputs

                if automatic_throttle.reason != last_automatic_reason:
                    print("AUTO throttle:", automatic_throttle.reason)
                    last_automatic_reason = automatic_throttle.reason

            output_values, failed_outputs = mixer.mix(
                input_values,
                fresh,
                corrections,
                throttle_overrides,
                forced_failsafe,
            )
            outputs.write_all(output_values)

        if due(now, next_log):
            next_log = time.ticks_add(next_log, log_period)
            flags = 0
            if imu:
                flags |= FLAG_IMU
            if barometer:
                flags |= FLAG_BAROMETER
            if gnss and gnss.valid:
                flags |= FLAG_GNSS
            if any(fresh.values()):
                flags |= FLAG_RECEIVER
            if failed_outputs:
                flags |= FLAG_FAILSAFE
            if automatic_throttle.active:
                flags |= FLAG_AUTO_ACTIVE
            if automatic_throttle.override_latched:
                flags |= FLAG_AUTO_OVERRIDE
            logger.write(mode, flags, attitude, gyro, imu_temperature, barometer, gnss, input_values, outputs.last)

        # Fast blink means at least one output is in failsafe; slow blink means healthy.
        blink_period = 125 if failed_outputs else 500
        if due(now, blink_deadline):
            blink_state = not blink_state
            led.value(blink_state)
            blink_deadline = time.ticks_add(now, blink_period)

        time.sleep_ms(1)


main()

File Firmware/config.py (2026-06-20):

"""Plane-specific Guardrail FC configuration.

This is the only file that normally needs to change between airframes.  Connector
names describe the PCB as viewed from the component/silkscreen side: LEFT is the
odd-numbered signal pad (pad 1), RIGHT is the even-numbered signal pad (pad 2).
"""

# Receiver PWM limits and scheduling -------------------------------------------------
PWM_MIN_VALID_US = 750
PWM_MAX_VALID_US = 2250
PWM_FRAME_US = 20000
INPUT_TIMEOUT_MS = 120
CONTROL_HZ = 100
IMU_HZ = 200
BAROMETER_HZ = 25
LOG_HZ = 10

# Physical PCB pin map. Do not change this section for a different plane.
INPUT_PINS = {
    "J1_LEFT": 7,
    "J1_RIGHT": 8,
    "J2_LEFT": 9,
    "J2_RIGHT": 10,
    "J3_LEFT": 11,
    "J3_RIGHT": 12,
    "J4_LEFT": 13,
    "J4_RIGHT": 14,
    "J5_LEFT": 15,
    "J5_RIGHT": 16,
}

OUTPUT_PINS = {
    "J6_LEFT": 19,
    "J6_RIGHT": 20,
    "J7_LEFT": 21,
    "J7_RIGHT": 22,
    "J8_LEFT": 23,
    "J8_RIGHT": 24,
    "J9_LEFT": 25,
    "J9_RIGHT": 26,
    "J10_LEFT": 27,
    "J10_RIGHT": 28,
}

INPUT_ORDER = tuple(INPUT_PINS)
OUTPUT_ORDER = tuple(OUTPUT_PINS)

# Per-receiver calibration. Add only values that differ from these defaults.
DEFAULT_INPUT_CALIBRATION = {"min_us": 1000, "center_us": 1500, "max_us": 2000}
INPUT_CALIBRATION = {
    # "J1_LEFT": {"min_us": 988, "center_us": 1501, "max_us": 2012},
}

# Output routing ---------------------------------------------------------------------
#
# Every output may use either:
#   "source": "J1_LEFT"                         (one receiver channel), or
#   "sources": {"J1_LEFT": 1.0, "J2_LEFT": 1.0} (mixing/elevons/V-tail).
#
# "assist" mixes stabilization corrections into that output. Leave it empty for a
# pure pilot-command channel. "passthrough" copies the raw pulse exactly and ignores
# reversal, trim, mixing, and assist; v1 requires this on all J4/J5 throttle routes.
def _direct(source, assist=None, reverse=False, failsafe_us=1500):
    return {
        "source": source,
        "assist": assist or {},
        "reverse": reverse,
        "trim_us": 0,
        "min_us": 1000,
        "center_us": 1500,
        "max_us": 2000,
        "failsafe_us": failsafe_us,
        "passthrough": False,
    }


def _throttle(source):
    return {
        "source": source,
        "assist": {},
        "reverse": False,
        "trim_us": 0,
        "min_us": 1000,
        "center_us": 1500,
        "max_us": 2000,
        "failsafe_us": 1000,
        "passthrough": True,
    }


# Safe starter profile: each connector side controls the same side of its paired
# output connector. J4/J5 are raw pass-through except while guarded AUTO throttle is active.
OUTPUTS = {
    "J6_LEFT": _direct("J1_LEFT"),
    "J6_RIGHT": _direct("J1_RIGHT"),
    "J7_LEFT": _direct("J2_LEFT"),
    "J7_RIGHT": _direct("J2_RIGHT"),
    "J8_LEFT": _direct("J3_LEFT"),
    "J8_RIGHT": _direct("J3_RIGHT"),
    "J9_LEFT": _throttle("J4_LEFT"),
    "J9_RIGHT": _throttle("J4_RIGHT"),
    "J10_LEFT": _throttle("J5_LEFT"),
    "J10_RIGHT": _throttle("J5_RIGHT"),
}

# Flight assist ----------------------------------------------------------------------
# Start in PASSTHROUGH until directions and gains have been proven on the bench.
# To configure a conventional plane, assign the receiver channels below, add for
# example {"roll": 1.0} to each aileron output's "assist", reverse the sign on the
# opposite aileron, and then set DEFAULT_MODE to "ASSIST".
DEFAULT_MODE = "PASSTHROUGH"  # "PASSTHROUGH", "ASSIST", or "AUTO"

# Optional three-position mode channel. None means DEFAULT_MODE is fixed. With a mode
# channel: low=PASSTHROUGH, middle=ASSIST, high=AUTO.
MODE_CHANNEL = None
MODE_ASSIST_THRESHOLD_US = 1300
MODE_AUTO_THRESHOLD_US = 1700

CONTROL_AXES = {
    "roll": {"source": "J1_LEFT", "max_angle_deg": 45.0},
    "pitch": {"source": "J2_LEFT", "max_angle_deg": 30.0},
}

# PID output is a normalized surface correction (-1.0 to +1.0).
PID = {
    "roll": {"kp": 0.018, "ki": 0.002, "kd": 0.004, "limit": 0.45},
    "pitch": {"kp": 0.022, "ki": 0.003, "kd": 0.005, "limit": 0.45},
}
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

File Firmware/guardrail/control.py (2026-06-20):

"""Plane-independent surface mixing, attitude assist, and automatic throttle."""

import math


def clamp(value, low, high):
    return low if value < low else high if value > high else value


def normalized_input(pulse_us, calibration):
    center = calibration["center_us"]
    if pulse_us >= center:
        span = max(1, calibration["max_us"] - center)
    else:
        span = max(1, center - calibration["min_us"])
    return clamp((pulse_us - center) / span, -1.0, 1.0)


def pulse_from_normalized(value, definition):
    value = clamp(value, -1.0, 1.0)
    center = definition["center_us"]
    if value >= 0:
        pulse = center + value * (definition["max_us"] - center)
    else:
        pulse = center + value * (center - definition["min_us"])
    return int(clamp(pulse + definition.get("trim_us", 0), definition["min_us"], definition["max_us"]))


def calibration_for(name, default_calibration, calibrations):
    result = dict(default_calibration)
    result.update(calibrations.get(name, {}))
    return result


class PID:
    def __init__(self, settings):
        self.kp = settings["kp"]
        self.ki = settings["ki"]
        self.kd = settings["kd"]
        self.limit = settings["limit"]
        self.integral = 0.0

    def reset(self):
        self.integral = 0.0

    def update(self, error_deg, measured_rate_dps, dt):
        if dt <= 0 or dt > 0.25:
            self.reset()
            return 0.0
        self.integral = clamp(self.integral + error_deg * dt, -self.limit / max(self.ki, 0.000001), self.limit / max(self.ki, 0.000001))
        output = self.kp * error_deg + self.ki * self.integral - self.kd * measured_rate_dps
        return clamp(output, -self.limit, self.limit)


class AttitudeAssist:
    def __init__(self, axis_definitions, pid_definitions, default_calibration, calibrations):
        self.axes = axis_definitions
        self.pids = {axis: PID(pid_definitions[axis]) for axis in axis_definitions}
        self.default_calibration = default_calibration
        self.calibrations = calibrations
        self._axis_calibrations = {
            axis: calibration_for(definition["source"], default_calibration, calibrations)
            for axis, definition in axis_definitions.items()
        }

    def reset(self):
        for controller in self.pids.values():
            controller.reset()

    def update(self, inputs, fresh, attitude, gyro_dps, dt):
        correction = {"roll": 0.0, "pitch": 0.0}
        measurements = {"roll": attitude[0], "pitch": attitude[1]}
        rates = {"roll": gyro_dps[0], "pitch": gyro_dps[1]}
        for axis, definition in self.axes.items():
            source = definition["source"]
            if not fresh.get(source, False):
                self.pids[axis].reset()
                continue
            calibration = self._axis_calibrations[axis]
            command = normalized_input(inputs[source], calibration)
            desired_deg = command * definition["max_angle_deg"]
            correction[axis] = self.pids[axis].update(desired_deg - measurements[axis], rates[axis], dt)
        return correction


class AutoThrottle:
    """Guarded altitude-hold throttle controller.

    Pressure altitude is the primary feedback. IMU attitude adds turn/climb
    feed-forward and GNSS ground speed can add an optional, deliberately bounded term.
    """

    def __init__(self, settings):
        self.settings = settings
        self.active = False
        self.override_latched = False
        self.reason = "not selected"
        self.target_altitude_m = None
        self.command_us = None
        self.altitude_source = None
        self.integral_us = 0.0
        self.vertical_speed_mps = 0.0
        self._last_altitude_m = None
        self._last_altitude_revision = None
        self._sample_elapsed_s = 0.0

    def disengage(self, reason="not selected"):
        self.active = False
        self.override_latched = False
        self.reason = reason
        self.target_altitude_m = None
        self.command_us = None
        self.altitude_source = None
        self.integral_us = 0.0
        self.vertical_speed_mps = 0.0
        self._last_altitude_m = None
        self._last_altitude_revision = None
        self._sample_elapsed_s = 0.0

    def abort(self, reason):
        self.active = False
        self.command_us = None
        self.reason = reason

    def engage(self, altitude_m, altitude_source, altitude_revision, pilot_throttle_us):
        self.disengage()
        if not self.settings["enabled"]:
            self.reason = "disabled in config"
            return False
        self.target_altitude_m = self.settings["target_altitude_m"]
        if self.target_altitude_m is None:
            self.target_altitude_m = altitude_m
        self.altitude_source = altitude_source
        # Start at the live pilot pulse; normal AUTO limits are approached through the
        # configured slew rate so engagement does not create a throttle step.
        self.command_us = pilot_throttle_us
        self._last_altitude_m = altitude_m
        self._last_altitude_revision = altitude_revision
        self.active = True
        self.reason = "active"
        return True

    def update(
        self,
        altitude_m,
        altitude_source,
        altitude_revision,
        attitude,
        ground_speed_mps,
        pilot_throttle_us,
        dt,
    ):
        if not self.active:
            return None
        if pilot_throttle_us >= self.settings["pilot_override_us"]:
            self.active = False
            self.override_latched = True
            self.command_us = None
            self.reason = "pilot override latched"
            return None
        if altitude_source != self.altitude_source:
            self.abort("altitude source changed")
            return None
        if dt <= 0 or dt > 0.25:
            self.abort("control timing fault")
            return None

        self._sample_elapsed_s += dt
        if altitude_revision != self._last_altitude_revision and self._sample_elapsed_s > 0.005:
            measured_speed = (altitude_m - self._last_altitude_m) / self._sample_elapsed_s
            alpha = self.settings["vertical_speed_filter_alpha"]
            self.vertical_speed_mps = alpha * self.vertical_speed_mps + (1.0 - alpha) * measured_speed
            self._last_altitude_m = altitude_m
            self._last_altitude_revision = altitude_revision
            self._sample_elapsed_s = 0.0

        altitude_error = self.target_altitude_m - altitude_m
        self.integral_us += self.settings["altitude_ki_us_per_m_s"] * altitude_error * dt
        limit = self.settings["integral_limit_us"]
        self.integral_us = clamp(self.integral_us, -limit, limit)

        throttle = self.settings["cruise_us"]
        throttle += self.settings["altitude_kp_us_per_m"] * altitude_error
        throttle += self.integral_us
        throttle -= self.settings["vertical_speed_damping_us_per_mps"] * self.vertical_speed_mps
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

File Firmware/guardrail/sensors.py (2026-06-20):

"""Drivers for the sensors wired to the Guardrail FC PCB."""

import math
import struct
import time


def _signed(value, bits):
    sign = 1 << (bits - 1)
    return value - (1 << bits) if value & sign else value


def _axis_transform(values, mapping):
    return tuple(values[source] * sign for source, sign in mapping)


class ICM42688:
    ADDRESS = 0x68  # U5 SDO/SA0 is tied low.
    WHO_AM_I = 0x75
    EXPECTED_ID = 0x47

    def __init__(self, i2c, axis_map, alpha=0.98, bias=(0.0, 0.0, 0.0)):
        self.i2c = i2c
        self.axis_map = axis_map
        self.alpha = alpha
        self.bias = list(bias)
        self.roll = 0.0
        self.pitch = 0.0
        self.accel_g = (0.0, 0.0, 1.0)
        self.gyro_dps = (0.0, 0.0, 0.0)
        self.temperature_c = 0.0
        self.last_us = None
        self.ready = False
        self._configure()

    def _read(self, register, count=1):
        return self.i2c.readfrom_mem(self.ADDRESS, register, count)

    def _write(self, register, value):
        self.i2c.writeto_mem(self.ADDRESS, register, bytes((value,)))

    def _configure(self):
        if self._read(self.WHO_AM_I, 1)[0] != self.EXPECTED_ID:
            raise OSError("ICM-42688-P WHO_AM_I mismatch")
        self._write(0x11, 0x01)  # DEVICE_CONFIG: soft reset
        time.sleep_ms(10)
        self._write(0x4E, 0x0F)  # PWR_MGMT0: accel and gyro low-noise modes
        time.sleep_ms(50)
        self._write(0x4F, 0x47)  # +/-500 dps, 200 Hz
        self._write(0x50, 0x47)  # +/-4 g, 200 Hz
        self.ready = True

    def read_raw(self):
        # TEMP, ACCEL XYZ, GYRO XYZ are contiguous and big-endian.
        raw = struct.unpack(">7h", self._read(0x1D, 14))
        accel = _axis_transform(tuple(value / 8192.0 for value in raw[1:4]), self.axis_map)
        gyro = _axis_transform(tuple(value / 65.5 for value in raw[4:7]), self.axis_map)
        temperature = raw[0] / 132.48 + 25.0
        return accel, gyro, temperature

    def calibrate_gyro(self, samples=200):
        totals = [0.0, 0.0, 0.0]
        for _ in range(samples):
            _, gyro, _ = self.read_raw()
            for axis in range(3):
                totals[axis] += gyro[axis]
            time.sleep_ms(5)
        self.bias = [total / samples for total in totals]
        self.last_us = None

    def update(self):
        accel, gyro, temperature = self.read_raw()
        gyro = tuple(gyro[index] - self.bias[index] for index in range(3))
        now = time.ticks_us()
        if self.last_us is None:
            dt = 0.0
        else:
            dt = time.ticks_diff(now, self.last_us) / 1000000.0
        self.last_us = now

        ax, ay, az = accel
        accel_roll = math.degrees(math.atan2(ay, az))
        accel_pitch = math.degrees(math.atan2(-ax, math.sqrt(ay * ay + az * az)))
        if dt <= 0 or dt > 0.1:
            self.roll, self.pitch = accel_roll, accel_pitch
        else:
            self.roll = self.alpha * (self.roll + gyro[0] * dt) + (1.0 - self.alpha) * accel_roll
            self.pitch = self.alpha * (self.pitch + gyro[1] * dt) + (1.0 - self.alpha) * accel_pitch

        self.accel_g = accel
        self.gyro_dps = gyro
        self.temperature_c = temperature
        return (self.roll, self.pitch), gyro


class SPA06:
    ADDRESS = 0x76  # U4 SDO is tied low.

    def __init__(self, i2c, sea_level_pa=101325.0):
        self.i2c = i2c
        self.sea_level_pa = sea_level_pa
        self.temperature_c = 0.0
        self.pressure_pa = 0.0
        self.altitude_m = 0.0
        self.sample_revision = 0
        self.ready = False
        self._read_coefficients()
        self._configure()

    def _read(self, register, count=1):
        return self.i2c.readfrom_mem(self.ADDRESS, register, count)

    def _write(self, register, value):
        self.i2c.writeto_mem(self.ADDRESS, register, bytes((value,)))

    def _read_coefficients(self):
        data = self._read(0x10, 18)
        self.c0 = _signed((data[0] << 4) | (data[1] >> 4), 12)
        self.c1 = _signed(((data[1] & 0x0F) << 8) | data[2], 12)
        self.c00 = _signed((data[3] << 12) | (data[4] << 4) | (data[5] >> 4), 20)
        self.c10 = _signed(((data[5] & 0x0F) << 16) | (data[6] << 8) | data[7], 20)
        self.c01 = _signed((data[8] << 8) | data[9], 16)
        self.c11 = _signed((data[10] << 8) | data[11], 16)
        self.c20 = _signed((data[12] << 8) | data[13], 16)
        self.c21 = _signed((data[14] << 8) | data[15], 16)
        self.c30 = _signed((data[16] << 8) | data[17], 16)

    def _configure(self):
        # 32 samples/s, 16x oversampling. Both result scale factors are 253952.
        temp_source = self._read(0x28, 1)[0] & 0x80
        self._write(0x06, 0x54)
        self._write(0x07, temp_source | 0x54)
        self._write(0x09, 0x0C)  # Required result shifts when oversampling > 8x.
        self._write(0x08, 0x07)  # Continuous pressure and temperature.
        time.sleep_ms(50)
        self.ready = True

    @staticmethod
    def _raw24(data):
        return _signed((data[0] << 16) | (data[1] << 8) | data[2], 24)

    def update(self):
        raw = self._read(0x00, 6)
        pressure_scaled = self._raw24(raw[0:3]) / 253952.0
        temperature_scaled = self._raw24(raw[3:6]) / 253952.0
        self.temperature_c = self.c0 * 0.5 + self.c1 * temperature_scaled
        self.pressure_pa = (
            self.c00
            + pressure_scaled * (self.c10 + pressure_scaled * (self.c20 + pressure_scaled * self.c30))
            + temperature_scaled * self.c01
            + temperature_scaled * pressure_scaled * (self.c11 + pressure_scaled * self.c21)
        )
        if self.pressure_pa > 1000:
            self.altitude_m = 44330.0 * (1.0 - (self.pressure_pa / self.sea_level_pa) ** 0.190294957)
        self.sample_revision += 1
        return self.pressure_pa, self.altitude_m

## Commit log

2026-06-19 PCB Done!
    [BOM.csv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]
2026-06-19 BOM Finished
    [BOM.csv]
2026-06-19 Update BOM
    [exampleBOM.csv]
2026-06-20 README + Zine + Firmware Done!
    [BOM.csv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]
